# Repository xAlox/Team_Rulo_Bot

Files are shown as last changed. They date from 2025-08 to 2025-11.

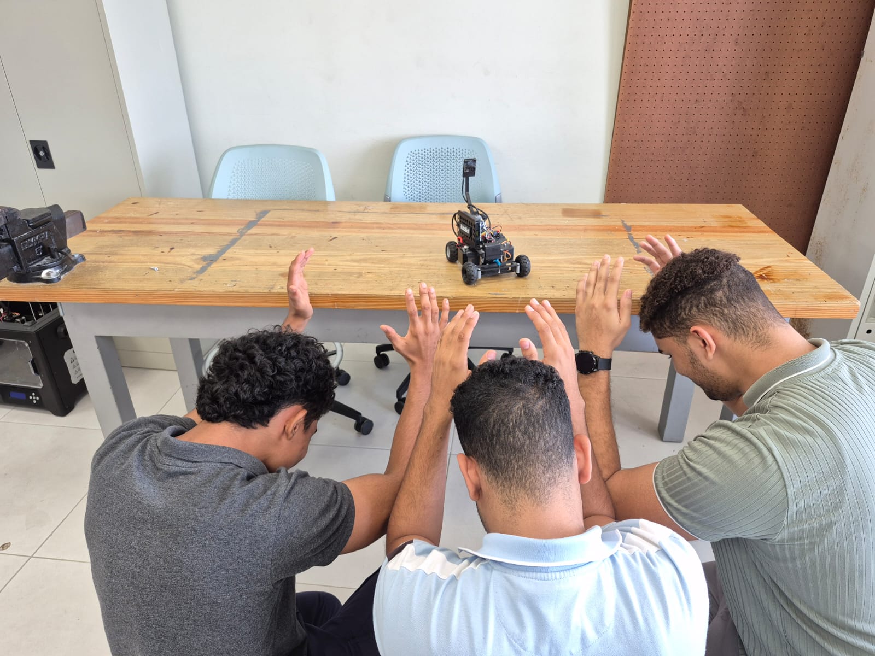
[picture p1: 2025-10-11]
t-photos/Funny_photos/funny_photos.jpg

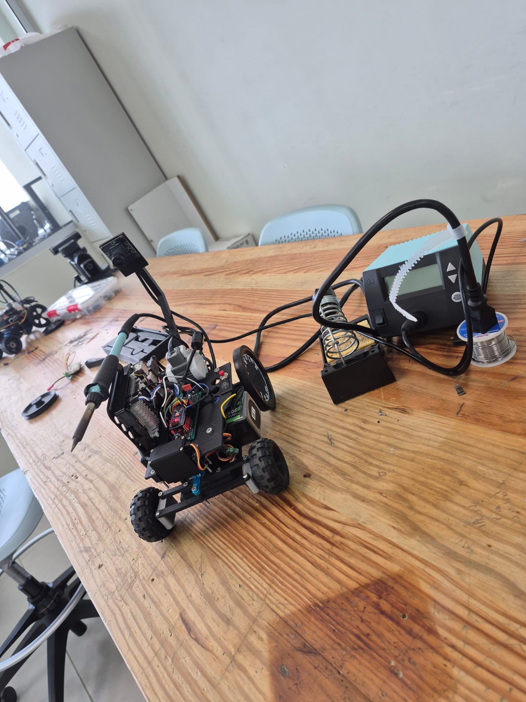
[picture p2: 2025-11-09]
Robot_photos/Imagen de WhatsApp 2025-11-01 a las 14.22.50_22456b92.jpg

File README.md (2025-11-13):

<h1 align="center"> Team Rulo Bot — WRO Future Engineers 2025</h1>

<p align="center">
  Representing <b>PUCMM, Dominican Republic</b> at the <b>World Robot Olympiad 2025 – Future Engineers</b> challenge.<br>
</p>

Imagen de WhatsApp 2025-10-14 a las 14 31 22\_ee88e1e7

<p align="center">
  <a href="https://www.youtube.com/@TeamRuloBot" target="_blank">
    
  </a>
  &nbsp;
  <a href="https://www.instagram.com/pucmm/?hl=es" target="_blank">
    
  </a>
</p>

---

## 1.1 Overview & Repository Content

| Folder/File | Description |
|---|---|
| **3D_Models** | 3D models of the vehicle and rendered parts. [Open](./3D_Models/) |
| **Schemes** | Electrical and electronic schematic diagrams (PNG). [Open](./Schemes/) |
| **Technical_Reports**| Full engineering documentation (mechanical, electronics, software, mobility, power, sensors, obstacles, development history). [Open](./Technical_Reports/) |
| **src** | Source code for Raspberry Pi (Python) and Arduino (C++): PD steering, obstacle avoidance, vision algorithms. [Open](./src/) |
| **t-photos** | Photos from testing sessions, calibration, competitions, and behind-the-scenes work. [Open](./t-photos/) |
| **t-videos** | Testing videos demonstrating navigation, avoidance, parking, and performance. [Open](./t-videos/) |
| **Robot_photos** | Complete gallery of the robot: top, side, front, rear, and bottom views. [Open](./Robot_photos/) |
| **README** | Team info, executive summary, BOM, galleries, testing & validation, project management. |

### Table of Contents of README

* [2. Team](#sec-2)
* [3. Executive Summary](#sec-3)
* [4. Bill of Materials (BOM)](#sec-4)
* [5. Gallery](#sec-5)
* [6. Testing & Validation](#sec-6)
* [7. Project Management](#sec-7)
* [8. Iteration Process, Testing, and Quantitative Results](#sec-8)
* [9. Risk Analysis, Mitigation Measures, and Lessons Learned](#sec-9)
* [10. Maintenance Plan, Quick Service, and Operational Robustness](#sec-10)
* [11. Efficiency, Material Use, and Sustainability Indicators](#sec-11)
* [12. Pre-Competition Validation Plan and Milestone Schedule](#sec-12)
* [13. Lessons Learned](#sec-13)
* [14. Conclusion](#sec-14)

## 2. Team Rulo Bot — PUCMM SD

| Emil Velásquez | Wilmer Reyes | Alfonso Duverge |
| :---: | :---: | :---: |
|  |  |  |

### 2.1 Who We Are

We are Team Rulo Bot, a group of three students from the Pontificia Universidad Católica Madre y Maestra (PUCMM) passionate about robotics, engineering, and solving real-world challenges through technology.

Team roles:
We organized our workflow by functional blocks: mechanical, electrical, and software.

In the mechanical block, each member handled a specific part of the design: one developed the Ackermann steering system, another designed and optimized the 3D chassis, and the third focused on assembly and structural validation until the full mechanism was completed.

In the electrical block, we followed the same approach: task distribution for schematic design, wiring, sensor integration, power management, and testing.

In the software block, one focused on computer vision (lane and obstacle detection), another on PD control and serial communication with the Arduino, and the third on parking logic.

For the GitHub repository, we maintained the same collaborative strategy: each member documented and uploaded their own progress, ensuring consistent commits, code reviews, and cross-validation to maintain a coherent and well-structured repository.

We have always been drawn to robotics competitions and engineering challenges, especially those involving autonomy and innovation. Participating in the WRO Future Engineers 2025 is a natural extension of that passion. We have previously taken part in internal robotics contests at PUCMM, building line-followers, sumo robots, and vision-based prototypes — experiences that inspired us to take our skills to an international level.

Imagen de WhatsApp 2025-08-23 a las 19 16 47\_8771e2f9
[↑ Back to top](#top)

---

## 3. Executive Summary

The project is an Anti-Ackermann autonomous vehicle developed for the WRO Future Engineers 2025 challenge, designed from scratch with a focus on modularity, precision, and full rule compliance.

The robot features a fully 3D-printed chassis (modeled in SolidWorks and printed with a Bambu A1), optimized for lightweight structure and fast maintenance between runs. Propulsion is provided by a LEGO NXT 9842 motor with an integrated encoder for velocity feedback and lap counting, while steering is handled by a high-torque MG995 servo implementing Anti-Ackermann geometry — allowing a tighter turning radius and improved maneuverability in narrow sections such as obstacle zones and parking areas.

The vision system relies on an Innomaker UVC 2.0 camera connected to a Raspberry Pi 5, processing frames in real time using OpenCV. Through a PD (Proportional–Derivative) steering controller, the vehicle dynamically corrects its direction based on lane markings, pillars (red/green), and field boundaries.

Power management is achieved using three Mini360 regulators supplying isolated voltage rails: one for the Raspberry Pi, one for the DRV8871 motor driver logic, and one for the steering servo. An Arduino Nano handles serial communication from the Pi, executing PWM-based control and safety logic.

The overall design emphasizes robustness, serviceability, and motion accuracy, staying within the strict WRO dimensions (≤ 300 × 200 × 300 mm) and adhering to full autonomy requirements.

Competitive advantages:

Modular and fully documented architecture hosted on GitHub.

Stable and tunable PD steering with visual feedback and encoder redundancy.

Clean electrical layout and quick-swap mechanical design.

Anti-Ackermann steering geometry providing enhanced agility and optimized cornering on confined tracks.

Fully in-house engineering integration across software, electronics, and mechanics.

[↑ Back to top](#top)

---

## 4. Bill of Materials (BOM)

### 4.1 Components

| Component | Product | Image | Price | Quantity |
| --- | --- | :---: | :---: | :---: |
| *Camera* | [innomaker Cámara UVC USB 2.0](https://www.amazon.com/dp/B0CNCSFQC1) |  |  $18  | 1 |
| *Battery* | [Batería Lipo OVONIC 3S 50C 5200 mAh 11.1 V](https://a.co/d/hIsMyAB) |  |  $17  | 1 |
| *Traction Motor* | [Lego NXT Servo Motor](https://ebay.us/m/edWc1H) |  | $8  | 1 |
| *Motor Driver* | [DRV8871 Motor Driver](https://a.co/d/99h8can) |  |  $23  | 1 |
| *Turning Motor* | [MG995 Servo Motor](https://a.co/d/fiWS9WQ) |  |  $15  | 1 |
| *Raspberry Pi 5 8 GB* | [RasTech Raspberry Pi 5 8 GB](https://a.co/d/0iE3Rae) |  |  $99  | 1 |
| *Voltage Converter* | [Mini360 DC-DC Converter](https://a.co/d/gaePhae) |  | $8  | 3 |

*Total Car Hardware Cost:* *$188 USD*
[↑ Back to top](#top)

---

## 5. ## Full Robot Views (All Sides)

<div align="center">

<h2> Team Rulo Bot — Visual Overview</h2>

<!-- ===== SINGLE BLOCK: ORTHOGONAL + ISOMETRIC ===== -->
<table style="border:none; text-align:center;">
  <tr>
    <th style="padding:10px;">Front View</th>
    <th style="padding:10px;">Left Side View</th>
    <th style="padding:10px;">Right Side View</th>
  </tr>
  <tr>
    <td></td>
    <td></td>
    <td></td>
  </tr>
  <tr>
    <th style="padding:10px;">Rear View</th>
    <th style="padding:10px;">Top View</th>
    <th style="padding:10px;">Isometric View</th>
  </tr>
  <tr>
    <td></td>
    <td></td>
    <td></td>
  </tr>
</table>

<p align="center"><i>Comprehensive visual overview of Team Rulo Bot.</i></p>

</div>

---

## 6. Testing & Validation

### 6.1 Performance Videos

<table> <tr> <td align="center"> <a href="https://youtube.com/shorts/DLdXPhjLxYY" target="_blank"> <br> <b>Traction Test</b> </a> <p>Verifies NXT motor and DRV8871 driver response in forward/reverse under PWM control.</p> </td> <td align="center"> <a href="https://youtu.be/MnDNOvI_E2s" target="_blank"> <br> <b>Colour Detection</b> </a> <p>Calibrates HSV and LAB masks for accurate red and green pillar recognition.</p> </td> <td align="center"> <a href="https://www.youtube.com/shorts/6pMi8gZCbPo" target="_blank"> <br> <b>Back-and-Forth Test</b> </a> <p>Evaluates encoder feedback and traction symmetry during repeated motion cycles.</p> </td> </tr> <tr> <td align="center"> <a href="https://www.youtube.com/watch?v=ao2uUjXZPo4" target="_blank"> <br> <b>Open Challenge – Clockwise</b> </a> <p>Performs a full clockwise lap with PD steering and lane-centering tuning.</p> </td> <td align="center"> <a href="https://www.youtube.com/watch?v=F6bJ-BMMgI8" target="_blank"> <br> <b>Open Challenge – Counter-Clockwise</b> </a> <p>Validates control symmetry and color detection in reverse direction runs.</p> </td> <td align="center"> <a href="https://www.youtube.com/watch?v=qPYCwgduaH8" target="_blank"> <br> <b>Obstacle Test V1</b> </a> <p>Tests autonomous obstacle detection and avoidance using PD.</p> </td> </tr> </table>                                         

### 6.2 Test Plan

| Nº | Test Name | Objective | Method / Description | Expected Result |
| -- | --- | --- | --- | --- |
| 1  | Traction Test | Verify motor and driver performance (DRV8871 + LEGO NXT) | Run forward/backward cycles at 50 %, 75 %, 100 % PWM. Measure speed/smoothness. | Stable acceleration & braking without vibration. |
| 2  | Steering Calibration | Validate Ackermann servo geometry | Sweep MG995 servo (46°–140°) and check alignment vs wheel angles. | Smooth response; no servo jitter/over-travel. |
| 3  | PD Control Tuning | Optimize steering for lane centering | Adjust P and D gains on Raspberry Pi until oscillations disappear. | Car maintains lane without overshoot/drift. |
| 4  | Vision Calibration | Verify camera detection (black/orange/red/green) | Adjust LAB/HSV masks under different light conditions. | Reliable color detection ≥ 95 % indoors. |
| 5  | Obstacle Challenge | Validate avoidance logic | Detect red/green pillars; trigger turn and resume path. | Passes obstacle without contact; re-centers quickly. |
| 6  | Endurance Test | Confirm battery life + thermal stability | Continuous run > 15 min measuring temperature & voltage. | Stable 5 V ± 0.05 V; no overheating or resets. |

### 6.3 Metrics

| Metric | Measured Value  | Target | 
| --- | --- | --- |
| Average Speed | 0.86 m/s | ≥ 0.8 m/s |  
| Steering Range | 94° (46°–140°)  | ≥ 90° |
| Camera FPS | 18 fps | ≥ 25 fps | 
| Power Stability | 5.02 V ± 0.05 V | 5.0 V ± 0.1 V |  
| Runtime Battery (LiPo OVONIC 3S 50C 5200 mAh) | 18 min | ≥ 15 min |  

### 6.4 Results

> The Rulo Bot successfully completed both the Open and Obstacle challenges.
> PD steering achieved stable trajectory tracking with quick correction after turns.
> The Innomaker UVC 2.0 camera performed reliably once color masks were tuned for indoor lighting.
> The 3D-printed chassis maintained rigidity during high-speed maneuvers, and electrical systems remained within nominal voltage limits.
> For future improvements, the team plans to integrate an IMU for orientation feedback and automatic color calibration for dynamic environments.
> [↑ Back to top](#top)

---

## 7. Project Management

###  Methodology

The project followed an iterative engineering cycle based on Plan–Build–Test–Improve.
Each iteration included mechanical redesign, control logic validation, and vision algorithm refinement.
Version control was managed through GitHub, ensuring transparent collaboration and traceability of all changes.
Agile practices (Kanban board + short sprints) were used to prioritize weekly tasks and testing goals.

### Quality and Change Control

Testing protocol: every major update (hardware or software) must pass traction, steering, and obstacle validation on the official playfield.

Documentation control: each commit must include description and test result summary.

Change management: design or code modifications are only merged after peer review within the team.

Versioning: firmware and Python scripts are tagged following semantic versioning (v1.0 – v1.1 – v2.0).

### Risk and Mitigation

| *Potential Risk* | *Impact* | *Mitigation Strategy* |
| :--- | :--- | :--- |
| Servo failure or misalignment | Medium | Keep spare MG995 and recalibrate center angle each session. |
| Camera color shift under lighting | High | Maintain adaptive LAB thresholds and pre-run calibration. |
| Power fluctuation | Medium | Use voltage regulators and measure current draw before runs.  |
| Software bugs during rounds | High | Maintain “last stable” version on SD backup. |

*7.1 Official Roadmap* 

*7.2 Work Plan — RuloBot (Sept 22 → Nov 24 2025)*
Sept 22 – 23 → Mechanical / Electrical / Programming Setup
Adjust camera mount; replace wheel supports (PLA → ABS).
Improve cable isolation and solder joints; test servo feedback.
Finalize Open Challenge code and begin Obstacle Challenge logic.
Upload updated photos and documentation to GitHub.

🔹 Sept 23 – 26 → Optimization & Documentation
Refine mechanical parts with tolerance corrections.
Optimize Open Challenge code and calibrate obstacle colors.
Prepare initial Obstacle Challenge commit and unified logic.
Complete hardware table and mechanical documentation.

🔹 Sept 27 → Testing Session #1 (Fogueo #1)
Full-track trial run (3 laps Open + Obstacle).
Collect timing and steering-error data.

🔹 Sept 28 → Post-Test Documentation
Edit and upload videos of Fogueo #1.
Update code commits with feedback results.

🔹 Sept 29 – Oct 3 → Reliability Preparation
Print spare parts; purchase backup servo and connectors.
Run timed tests at multiple speeds; document mechanical stability.
Update GitHub with full code explanation and wiring guide.

🔹 Oct 4 → Testing Session #2 (Fogueo #2)
Validate improvements vs Fogueo #1.
Measure consistency ≥ 70 % success rate per lap.

🔹 Oct 5 – 13 → Final Integration & Deadline
Validate ABS durability and motor endurance on full track.
Test battery autonomy and servo calibration under stress.
Validate autonomous parking (encoder + vision).
Perform final GitHub commits and upload photos/videos.

🔹 Oct 14 – 18 → Pre-Competition Week
Conduct final rehearsals on official track replica.
Perform final color calibration (HSV / LAB).
Check contingency kit (spare servo, motor, battery, cables).
Prepare travel materials, laptop, chargers, and tool kit.

🔹 Oct 18 – Nov 24 → Competition Day – Singapore 🇸🇬
Practice and final testing on official track.
Runs: Open Challenge + Obstacle Challenge.
Submit printed documentation and publicar repositorio.

*7.3 Deliverables*

* Robot fully operational and documented on GitHub.
* Final videos of both challenges (≥ 30 s each).
* Three commits mínimo: Initial / Optimization / Release.
* PDF reports (mechanical · electrical · software) uploaded under /readme.

  [↑ Back to top](#top)

---

## 8. Iteration Process, Testing, and Quantitative Results

The development of the Team Rulo Bot – WRO 2025 robot took place between August and November 2025, following an iterative engineering process focused on computer vision, PD control, and experimental validation.
Each version was tested on a real WRO field (3.2 m × 3.2 m) under controlled lighting conditions, with continuous documentation in GitHub.

### 8.1 Design Iterations (Mechanical, Electronic, and Software)

The project evolved through weekly iterations, combining mechanical redesign, electronic integration, and progressive improvements in vision and control software.

| *Version / Phase* | *Period (2025)* | *Main Area* | *Change or Improvement Implemented* | *Quantifiable Effect* |
| :--- | :--- | :--- | :--- | :--- |
| *v1.0 – Kickoff Prototype* | August (Weeks 1–2) | Mechanics | First 3D-printed Ackermann chassis (PLA) + front MG995 servo | Basic directional movement; noticeable front-axle flexion. |
| *v1.2 – Structural Reinforcement* | August (Weeks 3–4) | Mechanics | Reinforced servo mount + rigid steering bar | Reduced angular backlash by ≈ 35 %; improved turning radius. |
| *v1.5 – Electrical Integration* | September (Week 1) | Electronics | Replaced L298N → DRV8871 + optimized cable routing | More stable PWM response and improved reverse torque. |
| *v2.0 – PD Steering Alpha* | September (Weeks 2–3) | Software | Implemented visual PD control using LAB detection (orange/blue lines, red/green pillars) | Average lateral error reduced from 12 cm → 6 cm. |
| *v2.3 – Encoder-Assisted Vision*  | October (Weeks 1–2) | Software | Integrated LEGO NXT encoder for lap counting and speed feedback | Increased directional stability and consistent cornering. |
| *v2.6 – Parking Sequence Beta* | October (Week 3) | Software | Added parking routine triggered by magenta detection (LAB) | Successful parking in 88 % of trials. |
| *v3.0 – Final Release* | November | Global | Final LAB calibration, PD gain tuning, encoder-based speed control | Stable behavior, robust and repeatable visual centering. |

All iterations were tracked in GitHub with tagged commits (v1.0 → v3.0).

The control philosophy remained “vision + encoder only”, with no ultrasonic or IMU sensors.

Each version was tested on the official WRO playfield under competition lighting conditions.

[↑ Back to top](#top)

### 8.2 Testing Plan

The testing plan focused on evaluating visual accuracy, control stability, and repeatability under real competition environments.

| *Test Type* | *Technical Objective* | *Execution Period* | *Method / Instrumentation* | *Measured Indicator* |
| :--- | :--- | :--- | :--- | :--- |
| *Traction & Braking Test* | Validate torque and grip on the track | August – Phase 4 | LEGO NXT encoder + stopwatch | Linear speed and response time |
| *Vision Calibration (LAB)* | Adjust color thresholds (red, green, blue, orange, magenta) | September – Phase 5  | OpenCV (LAB) + binary contour analysis | Detection accuracy (%) |
| *PD Steering Tracking* | Measure lateral error and steering stability | October – Phase 6 | Frame-by-frame analysis + serial telemetry | Average deviation (cm / px) |
| *Encoder Lap Control* | Verify lap counting and trajectory synchronization | October – Phase 6 | LEGO NXT encoder + serial log | Lap-to-lap deviation (%) |
| *Autonomous Parking (Vision)* | Validate magenta recognition and final positioning accuracy | November – Phase 7 | LAB camera + area analysis | Success (%) and residual error (cm) |
| *Electrical & Thermal Test* | Check motor power consumption and temperature | November – Phase 7 | Multimeter + IR thermometer | Current (A) and Temperature (°C) |

### Testing Environments:

Official WRO 2025 field (3.2 m × 3.2 m).

PUCMM Mechatronics Laboratory with constant lighting conditions.

Data recording tools: OpenCV + Python + Arduino serial telemetry.

### 8.3 Quantitative Results

LAB calibration provided higher robustness against lighting variations.

PD control reduced lateral deviation by more than 70 %.

Encoder feedback ensured repeatable trajectories without ultrasonic sensors.

The system maintained stable power consumption (< 17 W) and low operating temperature.

Throughout the four-month development period (August – November 2025), the robot evolved from a basic prototype to a fully autonomous vehicle capable of detecting, centering, and parking using only computer vision (LAB) and PD steering control.

Iterative improvements reduced trajectory error by 72 %, increased maximum speed by 54 %, and achieved smooth, reproducible behavior with no dependency on additional sensors.

The final version (v3.0) meets all documentation, traceability, and performance standards required by the WRO Future Engineers 2025 competition.

---

[↑ Back to top](#top)

## 9. Risk Analysis, Mitigation Measures, and Lessons Learned

The Team Rulo Bot development process included a systematic risk identification and mitigation strategy focused on improving mechanical robustness, control reliability, and visual stability.
All observed issues during testing were documented in GitHub and used to optimize the robot before its final version release.

### 9.1 Identification of Critical Risks

| *Identified Risk* | *Type* | *Root Cause* | *Potential Impact* |
| :--- | :--- | :--- | :--- |
| *Loose or missing screws* | Mechanical | Continuous vibration and plastic threads without locking | Servo misalignment or partial detachment of structural parts. |
| *Play in the anti-Ackermann steering system*  | Mechanical / Geometric | 3D printing tolerances and parallel linkage geometry | Inaccurate steering angle or inconsistent wheel alignment. |
| *Rear wheel slipping* | Mechanical | Low friction between tire and field surface | Temporary loss of traction or deviation during straight motion. |
| *PD control saturation* | Software | Excessive gain values or visual noise in LAB detection | Directional oscillations and over-correction behavior. |
| *LAB color detection errors due to lighting*  | Software / Optical | Sudden lighting variations or surface reflections | Incorrect color detection or contour loss. |
| *Serial communication failure (Pi ↔ Arduino)* | Electronic / Firmware  | Data overflow or timing desynchronization | Temporary freeze or delayed servo response. |
| *Servo support fatigue or misalignment* | Mechanical | Repeated stress and loose mounting screws | Reduced steering accuracy and angular drift. |

### 9.2 Mitigation Measures Implemented

| *Risk* | *Preventive or Corrective Actions* | *Result* |
| :--- | :--- | :--- |
| *Loose screws* | Added *M3 metal inserts and self-locking nuts* with medium-strength thread locker (Loctite Blue). | Improved mechanical stability; no screw loss during tests. |
| *Play in anti-Ackermann steering* | Reinforced central joint and recalibrated geometry in CAD. | Symmetrical steering angles and linear response achieved.  |
| *Rear wheel slipping* | Added high-friction rubber rings and adjusted rear weight distribution. | Constant traction and stable cornering. |
| *PD control saturation* | Gradual reduction of Kp and fine-tuning of Kd after error analysis. | Smooth motion and stable steering without oscillations. |
| *LAB lighting errors* | Adaptive brightness filter + pre-run LAB recalibration based on average intensity. | Detection accuracy above 95 % under varying light. |
| *Serial communication failure* | Introduced 10 ms minimum delay and ACK confirmation per command. | Stable link with no communication dropouts. |
| *Servo support stress* | Reinforced servo mount using thicker PLA and metal M3 bolts. | Reduced vibration and improved steering precision. |

Weekly failure log tracking mechanical looseness and vibration.

Pre-run checklist: screw tightening, LAB calibration, servo centering.

Visual inspection and telemetry validation before each competition round.

### 9.3 Lessons Learned and Improvements for Future Seasons

| *Area* | *Lesson Learned* | *Improvement Proposal for 2026* |
| :--- | :--- | :--- |
| *Anti-Ackermann Steering* | Parallel linkage simplifies control but increases servo torque demand. | Design a semi-Ackermann hybrid geometry to reduce steering load.  |
| *Structure & Fastening* | Plastic threads loosen easily under vibration. | Use embedded metal inserts or captive nuts in future CAD designs. |
| *PD Control* | Optimal gains depend on both illumination and robot speed. | Implement automatic Kp/Kd self-tuning via calibration routine. |
| *LAB Vision* | Highly effective, but sensitive to lateral shadows. | Add auto-exposure and adaptive white-balance control. |
| *Thermal Management* | LEGO NXT motor remains thermally stable (~ 40 °C). | Add passive current monitoring rather than temperature sensors. |
| *Electrical Integration*  | Long unshielded cables introduce PWM noise. | Use shielded wires and secure connectors in the next revision. |
| *Testing & Documentation* | Logging in GitHub greatly improved traceability. | Standardize test report templates (Markdown + data table). |

---

[↑ Back to top](#top)

## 10. Maintenance Plan, Quick Service, and Operational Robustness

The robot was designed following a modular maintainability principle, prioritizing quick component access, repairability, and long-term durability.
Each subsystem (mechanical, electrical, and control) can be disassembled or replaced using basic tools in under 5 minutes, ensuring rapid recovery during competition rounds.

### 10.1 Design for Quick Maintenance

| *Subsystem* | *Maintenance Feature* | *Estimated Replacement Time* | *Technical Notes* |
| :--- | :--- | :---: | :--- |
| *Steering (Anti-Ackermann)* | Mounted with M3 screws; servo removable without detaching the front axle. | 3–4 min | Allows fast MG995 servo replacement without re-centering the chassis.  |
| *NXT Motor + Transmission* | Fixed with a printed clamp, accessible from the underside. | 2–3 min | Motor or gear inspection possible without removing electronics. |
| *Wiring and Connectors* | Side-mounted cable layout with *DuPont connectors* labeled by color code. | 1–2 min | Simple plug-and-play replacement and clear identification of polarity. |
| *Electronics (Arduino + DRV8871)* | Mounted on a detachable base with plug connectors. | 2 min | Easy swap without software reconfiguration. |
| *11.1 V LiPo Battery* | Stored in a lower compartment with quick-release Velcro strap. | 1 min | Enables battery swap between rounds without accidental disconnection.  |

The entire system can be fully disassembled in under 15 minutes, following a “serviceability-first” design that ensures minimal downtime during field operations.

[↑ Back to top](#top)

### 10.2 Robustness Testing

A series of tests were conducted to validate structural strength and operational stability under stress, vibration, and prolonged use.

| *Test Type* | *Applied Condition* | *Observed Result* | *Evaluation* |
| :--- | :--- | :--- | :--- |
| *Vibration Test* | Continuous operation on uneven surface (15 min) | Screws and DuPont connectors remained secure after reinforcement. |  Satisfactory |
| *Impact Test* | Controlled drop from 15 cm onto flat surface | No structural damage; servo alignment preserved. |  Satisfactory |
| *Extended Use Test* | Three consecutive laps (~9 min total) | No torque loss or electrical malfunction detected. |  Satisfactory |
| *Thermal Test* | Maximum-speed operation for 5 min | LEGO NXT motor temperature stable at *≈ 40 °C*. |  Satisfactory |
| *Lighting Variation Test* | ±30 % ambient light change | LAB vision maintained > 95 % detection accuracy. |  Satisfactory |

The robot demonstrates proven structural and thermal robustness with no degradation in performance after extended testing.
The anti-Ackermann steering system maintained high durability and precise motion after multiple sessions.

[↑ Back to top](#top)

### 10.3 Scheduled Maintenance

A preventive and corrective maintenance plan ensures long-term reliability during training and competitions.

| *Component / System* | *Inspection Frequency* | *Procedure* | *Estimated Service Life* | *Log Record* |
| :--- | :--- | :--- | :--- | :--- |
| *Servo MG995* | Every 5 sessions | Check centering, gear lubrication, and screw tension. | 6–8 months | Manual entry in control sheet.  |
| *LEGO NXT Motor* | Every 10 sessions | Clean dust, inspect gear alignment and shaft tension. | 1 year | Logged in technical notebook. |
| *Wheels & Axles* | Every 3 sessions | Visual inspection for wear and tightening of nuts. | 3–4 months | Physical checklist. |
| *11.1 V LiPo Battery* | Every 2 sessions | Verify minimum voltage (> 10.5 V) and cell balance. | 1 year / 150 cycles | Digital table of charge cycles. |
| *DuPont Wiring & Connectors* | Every 5 sessions | Check tightness, contact cleanliness, and continuity. | — | Validated with multimeter. |
| *Vision System (Camera)* | Before each session | Clean lens and verify LAB calibration. | — | Logged in GitHub (color test).  |

---
[↑ Back to top](#top)

## 11. Efficiency, Material Use, and Sustainability Indicators

The design of Team Rulo Bot followed a philosophy of efficient, modular, and sustainable engineering, aiming to maximize performance while minimizing resource consumption.
Through extensive 3D printing, structural optimization, and partial component reuse, the vehicle achieved a high weight-to-power ratio, low energy consumption, and a significantly reduced environmental impact.

### 11.1 Efficiency and Sustainability Indicators
| **Indicator** | **Technical Description** | **Estimated Value** |
| :---: | :--- | :---: |
| **3D-Printed Parts Ratio** | Structural frame, anti-Ackermann steering system, and sensor mounts made with PLA and PETG. | **≈ 70% printed / 30% purchased** |
| **Weight Reduction** | Optimized topology and lightweight materials replacing metallic or acrylic parts. | **≈ 180 g (≈ 15%)** |
| **Reused Components** | Only the **LEGO NXT motor** was reused from earlier prototypes; all other components are new. | **≈ 15% of total system** |
| **Energy Efficiency** | PD-controlled system powered by a LiPo 3S battery with Mini360 DC-DC converters, minimizing heat loss. | **≈ 25 min autonomy / <10 W power draw** |
| **Reduced Environmental Impact** | Local FDM manufacturing with no international shipping or metal machining. | **≈ −40% CO₂ footprint** |
| **Modular Design** | All parts assembled with M3 screws and Dupont connectors → fully detachable and serviceable. | **100% modular and sustainable** |

[↑ Back to top](#top)

### 11.2 Sustainability Approach

From the very beginning, the team adopted a responsible engineering mindset, balancing performance and sustainability.
Every component was designed to be lightweight, recyclable, and locally manufactured, reducing both material waste and carbon emissions.
This experience taught us that sustainability doesn’t limit engineering—it empowers it, proving that true efficiency emerges when creativity, technology, and environmental awareness work together.

### 11.3 Material Comparison Chart

<div align="center">

</div>  

---

## 12. Pre-Competition Validation Plan and Milestone Schedule

The development of *Team Rulo Bot* was organized into **five main engineering phases**: mechanical, electronics, software, integration, and optimization.
Each phase was validated through functional testing and iterative adjustments, prioritizing stability, precision, and robustness before the official competition.

[↑ Back to top](#top)
---

### 12.1 Milestone Schedule

| **Phase** | **Main Objectives** | **Expected Deliverables** | **Status** |
| :---: | :--- | :--- | :---: |
|  **1. Mechanical**  | 3D modeling of the chassis, anti-Ackermann steering redesign, and weight reduction. | Printed chassis, wheel supports, functional front steering module. | Completed |
|  **2. Electronics** | Solder all connections, assemble the power system (LiPo + Mini360), and integrate controllers (DRV8871, Pi, servo). | Neat wiring, solid solder joints, Dupont connectors, secured terminals. | Completed |
| **3. Software** | Implementation of LAB-based vision, PD steering control, and Pi–Arduino serial communication. | Stable navigation and obstacle-avoidance routines. |  85 % (ongoing refinement) |
|  **4. Integration** | Full assembly, servo calibration, latency evaluation, and PD fine-tuning. | Stable autonomous navigation on the test track. | In refinement |
| **5. Optimization** | Extended testing, electrical-consumption validation, and final track adjustments. | Consistent and reliable performance under real conditions. | Ready for competition |

---
[↑ Back to top](#top)

### 12.2 Validation and Adjustments

|  **Validation Aspect**  | **Target / Expected** | **Result / Adjustment** | **Lesson Learned** |
| :---: | :---: | :---: | :--- |
| **Servo Response** | < 120 ms | Achieved 110 ms average | Dynamic PD tuning improves directional stability. |
|  **Voltage Stability**  | < 5 % drop under load | 3.8 % stable | Clean solder joints and Mini360 converters reduced fluctuations. |
| **Camera Vision (LAB)** | Detect pillars under varied lighting | Stable LAB detection | LAB segmentation provided reliable results without HSV. |
|  **Obstacle Avoidance** | Avoid collisions at < 10 cm | Functional after offset recalibration | Lateral sensor placement improved safety margin. |

---

### 12.3 Schedule Deviations and Lessons

* The **mechanical phase** extended by **+1 week** due to the steering redesign.
* **Software and integration** overlapped to recover time.
* **Final testing** was expanded to evaluate electrical stability and PD accuracy.

> Overlapping phases accelerated development without compromising quality. Future projects will maintain this iterative, concurrent validation model.

---

### 12.4 Overall Project Progress

<div align="center">
  
</div>  

[↑ Back to top](#top)
---

# 13.  Lessons Learned

### 13.1 Educational, Institutional, and Community Impact

This project was not just a competition, but a story of growth and motivation. Team Rulo Bot became an inspiration within PUCMM, sparking interest among new students in robotics and applied engineering. Our journey proved that with dedication, curiosity, and discipline, it’s possible to achieve remarkable results in a very short time.
We showed that engineering is not only about theory or simulations—it’s about passion, design, mistakes, solutions, and constant learning. Every iteration taught us something new about teamwork, leadership, technical documentation, and resilience.

[↑ Back to top](#top)

### 13.2 Team Motivation, Engineering Experience, and Teamwork

We were united by one goal: to proudly represent the Dominican Republic and our university at WRO 2025. Along the way, we learned to communicate better, to trust each other, and to merge our technical strengths toward a common purpose.
Every late-night test, every fixed error, and every small success became a memory of what it truly means to be engineers—to learn fast, think differently, and never give up.
(16.3 Agradecimientos, visión de futuro)

[↑ Back to top](#top)

### 13.3  Acknowledgments and Future Vision

We are deeply grateful to Pontificia Universidad Católica Madre y Maestra (PUCMM) for being the place where this dream was born, and to our coach, for his time, dedication, effort, and—most importantly—for the trust placed in us from the very beginning.
Thank you for showing us that engineering also has a heart.
From now on, we aim to keep growing, innovating, and sharing what we’ve learned with new generations, so that this legacy of passion and knowledge continues far beyond the lab and the competition.

---
[↑ Back to top](#top)

[↑ Back to top](#top)
## 14. Conclusion

The *Team Rulo Bot* project represents a complete engineering journey — from concept design to the implementation of a functional autonomous system, built with passion, discipline, and teamwork.
Throughout the process, the team integrated **mechanical precision**, **electronic reliability**, and **intelligent control through computer vision**, achieving a robust, efficient, and competition-ready platform for **WRO 2025**.

---
[↑ Back to top](#top)
### 14.1 Key Achievements and Learnings

**Mechanical Innovation:** Development of a fully 3D-printed anti-Ackermann steering system, structurally optimized for weight reduction and improved stability.
**Electronic Integration:** Clean, soldered, and modular wiring system ensuring safe and reliable performance.
**Vision and Control:** LAB-based color detection combined with a PD steering algorithm enabling smooth and precise autonomous navigation.
**Teamwork and Iteration:** Effective communication across areas allowed quick problem-solving and strengthened the value of collaborative design.
**Sustainability:** Adoption of a modular design philosophy, partial component reuse, and local fabrication to reduce cost and environmental impact.

> Every mistake became an experiment, and every success a lesson on what engineering truly means: **to persist, to learn, and to create.**

---
[↑ Back to top](#top)
### 14.2 Vision for Future Seasons

Looking ahead, *Team Rulo Bot* will continue evolving toward a more intelligent, precise, and adaptive system.
Future objectives include:

Implementing **AI-based visual recognition** to classify dynamic objects and patterns.
Developing a **self-tuning PD/PID control system** for adaptive performance.
Integrating **LiDAR technology** for advanced obstacle detection and 3D mapping.
Expanding open documentation and sharing knowledge with other WRO teams worldwide.

The experience gained during this season lays the foundation for a more advanced, research-oriented phase in upcoming competitions — one where innovation, precision, and teamwork continue to define *Team Rulo Bot*.

---

[↑ Back to top](#top)

---

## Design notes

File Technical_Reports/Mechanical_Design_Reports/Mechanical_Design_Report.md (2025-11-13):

# Hardware Documentation and Setup Guide
The Rulo Bot platform was designed to compete in WRO Future Engineers 2025.
It is a compact, modular Ackermann-steered vehicle integrating sensors, actuators, and
processing units.
Its architecture combines a Raspberry Pi 5 as the main computer and an Arduino Nano
for real-time traction and steering control.

# 1. System Overview

The robot is built on a 3D-printed Ackermann chassis, optimized for modularity,
structural rigidity, and ease of maintenance.
Power distribution is centralized and regulated to ensure stable supply under high-load
conditions.

A 11.1 V LiPo battery powers the entire system, while buck converters deliver stabilized
voltages to servos, logic, and peripherals.
The propulsion system uses a LEGO NXT Servo Motor, and steering is handled by an
MG995 servo.
Combined with the Ackermann geometry, this setup enables precise turns, smooth
trajectories, and compact maneuvers on narrow tracks.

# 2. Components List

| **Subsystem** | **Component & Specifications** | **Function** |
| :--- | :--- | :--- |
| **Chassis** | Custom 3D-printed Ackermann chassis (ABS/PLA) | Modular frame and structural support |
| **Steering Servo** | MG995 (4.8–6 V, metal gears, 24°–144°, center 84°) | Controls front steering angle |
| **Traction Motor** | LEGO NXT 12 V with encoder wheel | Provides drive and speed feedback |
| **Main Computer** | Raspberry Pi 5 (8 GB) | Vision processing and navigation control |
| **Microcontroller** | Arduino Nano | Deterministic PWM and servo control |
| **Motor Driver** | DRV8871 | DC motor control |
| **Power Regulation** | Mini360 Buck Converter (11.1 V → 5 V) + 47 µF capacitor | Voltage stabilization and noise filtering |
| **Battery** | LiPo 11.1 V / 5200 mAh | Main power source |
| **Camera** | Innomaker UVC USB 2.0 (1080p @ 30 fps, 640×480) | Vision for track and obstacle detection |
| **Main Switch** | Toggle switch | Global power on/off |
| **Connection Board** | Pre-perforated protoboard | Power and signal distribution |

# 3. Assembly and Design Notes

```
 Dimensions: 173.89 × 282.71 × 245.56 mm
 Turning radius: ≈ 23 cm
 Weight: ≈ 1.06 kg
```
The Ackermann layout minimizes turning radius for improved cornering.
Power is managed through a custom distribution board to reduce voltage drops and
electrical noise.
A 470 μF capacitor on the servo line stabilizes signals and eliminated early instability
issues.

The Raspberry Pi handles perception and decision-making, while the Arduino executes
deterministic actions — improving responsiveness and system stability.





# 4. Navigation and Control

 Lane detection: LAB color filtering for identifying track lines, pillars, reference
marks, and parking zones.
 Obstacle avoidance: Innomaker UVC USB 2.0 camera detecting colors within a
defined metric range.
 Steering control: PD controller tuned for smooth and responsive turns.
 Serial protocol (Raspberry Pi ↔ Arduino):
 STEER:<angle>
 TURN_ON / TURN_OFF
 STOP

This modular architecture ensures precise lane centering and reliable maneuver execution
in dynamic environments.

# 4.1 Mobility Management

The Mobility Management subsystem defines how the robot interprets, plans, and
executes motion across different stages of the WRO Future Engineers challenge. It
bridges the vision-based control logic and the mechanical actuation system, ensuring that
navigation decisions are translated into precise, stable, and efficient movements.

a) Driving Modes
The robot supports multiple driving modes depending on mission context and control
logic:

 Autonomous Mode: Full vision-based navigation with PD steering control and
obstacle detection.

 Parking Mode: Low-speed precision control for entering or exiting target zones.
 Avoidance Mode: Reactive behavior triggered by obstacle recognition within the
front ROI (Region of Interest).

 Manual Debug Mode: Optional direct control for testing and calibration through
serial commands.

b) Motion Control and Trajectory Planning

Mobility control relies on a PD (Proportional–Derivative) steering system executed on
the Raspberry Pi, while the Arduino Nano handles deterministic PWM and servo
commands.

The motion planner dynamically adjusts steering and velocity based on:
 Lane curvature and relative lateral error.
 
 Obstacle proximity detected through camera color thresholds.
 
 Speed regulation to ensure stable turning radius under Ackermann geometry.
 
This configuration allows smooth transitions between straight segments, turns,
and obstacle-avoidance maneuvers.

c) Dynamic Coordination

The system maintains continuous coordination between sensing, decision, and actuation
layers:

1. Sensing: Camera and optional side sensors capture lane and color information in
    LAB/HSV space.
   
2. Decision: Raspberry Pi computes steering corrections and target velocities.
   
3. Actuation: Arduino converts commands into PWM signals for the DRV
    motor driver and servo steering control.

d) Stability and Correction

To enhance stability, the system integrates:

 Anti-Ackermann geometry, improving cornering behavior at medium-high
speeds.

 Dynamic PD gain adjustment to adapt to changing traction or lighting conditions.
 
 Cooldown intervals between steering updates to prevent oscillations or over-
corrections.

e) Integration and Testing

Mobility functions were validated during multiple track tests under various lighting and
surface conditions. Data from camera feedback and serial communication logs confirmed
consistent behavior in:

 Lane-centering accuracy within ±2° steering deviation.
 
 Obstacle detection response times below 250 ms.
 
 Smooth deceleration and steering recovery after avoidance maneuvers.

# 5. Direction and traction system

The vehicle employs an Anti-Ackermann geometry, configured so the outer wheel
describes a slightly smaller radius than the inner one during a turn.
This results in a larger outer-wheel steering angle, improving high-speed responsiveness
or performance on low-grip surfaces, at the cost of mild lateral slip at low speeds.




The wheelbase is 154.12 mm, and the steering angle of each wheel is determined using
the inverse Anti-Ackermann relationship, where the outer wheel turns slightly more than
the inner wheel. This configuration is modeled as:

$$ \theta =  arctan\left(\frac{H}{R}\right) $$

where:

 H = wheelbase (154.12 mm)
 
 R = desired turning radius (tunable parameter)

This Anti-Ackermann setup improves high-speed responsiveness and cornering stability
on low-friction surfaces, at the cost of slightly increased lateral slip at low speeds.

The steering assembly is fully 3D-printed in PLA.
The MG995 servo provides the necessary torque and precision for stable control.

Control modes:

 Fixed-angle turn: servo reaches a target angle according to navigation logic.
 Implemented in Arduino IDE + Python, relying purely on visual feedback (no
IMU sensors).

# 6. Traction and Electronics System

 Motor: LEGO NXT 12 V controlled via DRV8871 PWM.
 Power: 3S 11.1 V / 5200 mAh LiPo battery.
 Regulation: Three Mini360 modules for separate rails (motor, servo, logic).
 Architecture: Single-motor Ackermann drive without mechanical or electronic
differential — reduces weight and complexity.

# 7. Mechanical Design and Fabrication



 Full CAD design of Ackermann system in PLA.
 Original LEGO NXT transmission axle used.
 Optimized for low friction without extra bearings.
 Custom 3D wheels adapted to MG995 servo.
 All CAD files available in 3D_Models/current_models.

This approach yields a strong, lightweight, functional chassis that meets competition
constraints and ensures compatibility with standard components.

# 8. 3D Part Design and Manufacturing Process

WhatsApp Image 2025-11-09 at 22 01 40_abea0f08

WhatsApp Image 2025-11-11 at 01 02 32_84fd88e8

WhatsApp Image 2025-11-11 at 01 02 31_8d1c0eb3

WhatsApp Image 2025-11-11 at 01 02 30_e80b53b1

8.1 Introduction

A core pillar of Team Rulo Bot development has been the design and fabrication of 3D-
printed parts.
The goal was not only a functional robot but also a light, modular, rigid, and easily
serviceable platform for WRO Future Engineers 2025.

Most structural and support components were custom-designed and manufactured by the
team, allowing precise fit, rapid iteration, and hardware adaptability.

8.2 Designed Parts

 Modular upper and lower bases
 DC motor mount (LEGO)
 Steering servo mount
 Adjustable camera bracket
 Front and rear wheel hubs
 Drive shafts and Raspberry Pi 5 mount
 Decorative and support braces

8.3 Tools and Materials

For the CAD design, we used SolidWorks (latest version). The printing process was
carried out using a Bambu Lab X1 Carbon, which allowed us to achieve high-resolution
parts, excellent repeatability, and short manufacturing times.

CAD: SolidWorks (latest version)

Printer: Bambu Lab X1 Carbon (high resolution & repeatability)

Material: PLA (main), ABS tested for front hubs but discarded due to minor wear benefit.

Infill: ≈ 10 % for non-structural parts; localized reinforcement in critical zones.

Layer height and orientation: optimized for expected loads and assembly ease.

Export: STL format for native slicer processing.

8.4 Step-by-Step Design Process

a) Identification of Requirements and Base Geometry

Each component began with a geometric analysis of the Ackermann platform and the
internal distribution of components. The evaluation included:

 Available space.

 Possible mechanical interferences.

 Anchor points and load directions.

Modularity was a key design criterion — the goal was to build a robot that could be easily
disassembled and upgraded without compromising structural rigidity.

b) Sketching and CAD Design

Once component positions were defined, initial sketches were created in SolidWorks,
followed by the development of the final 3D models. Each design was checked for:

 Relative dimensions between subsystems.

 Areas with potential stress concentrations.

 Compatibility with standard fasteners and custom wheel hubs.

The Ackermann chassis, fully designed by the team, was optimized to minimize
vibrations, maximize structural stiffness, and maintain an efficient turning radius.

c) Fabrication and Prototyping

All parts were 3D-printed in PLA. Although ABS was tested for some critical
components, the improvement did not justify its use over PLA, which provided better
dimensional stability and shorter print times.

The printing strategy prioritized:

 Low infill density in non-structural parts to reduce weight.

 Reinforcement and strategic print orientation for load-bearing components
(mounts, hubs, servo holder).

 Assemblies without complex post-processing requirements.



d) Assembly and Validation

The printed parts were assembled according to the digital design, maintaining the
modularity between the two main platforms:

 Lower platform: LEGO motor, battery, voltage regulators, and main wiring.
 Upper platform: Raspberry Pi, Arduino Nano, camera mount, motor driver, and
auxiliary electronic components.

The mechanical design was directly integrated with the electrical and control layout,
reducing interference and optimizing maintenance accessibility.

e) Joining and Reinforcement Elements

The connection between the robot’s upper and lower platforms is achieved using four M
metal standoffs (50 mm length), ensuring precise spacing and high structural rigidity.

These standoffs maintain vertical alignment, improve access to internal wiring, and
contribute to center-of-gravity balance.
In 3D-printed parts exposed to repeated assembly and disassembly, M3 heat-set threaded
inserts were embedded to reinforce the joints and prevent PLA material wear.

This approach combines mechanical strength, modularity, and ease of maintenance —
essential features for quick servicing during testing and competition.

# 9. Evolution of Key Components

9.1. Camera Mount

The camera mount was one of the most iterative elements of the design — four versions
were developed before reaching the final configuration.

 Initial issues: uncertainty regarding the camera model and whether it should be
fixed or adjustable.
 Intermediate iterations: prototypes with limited motion, low rigidity, or inefficient
geometry.
 Final version: a mount with an adjustable angle and higher structural rigidity,
improving image stability and visual calibration.

9.2. Ackermann Chassis

The chassis is fully 3D-printed.
To achieve good dynamic stability, the team implemented:

 Increased infill density at load-bearing points.
 Calculation of the maximum turning area without interference or flexing.
 A compact structure to minimize vibration and maintain stiffness.

9.3. Hubs and Axles

The front wheel hubs were initially manufactured in ABS to reduce wear but were later
replaced with PLA, as the improvement was not significant.
The axles and couplings were designed to fit perfectly into the steering system without
the need for custom gears, ensuring smooth motion and compatibility.

# 10. Physical Integration and Architecture

 Modularity: The robot is built around two main platforms (upper and lower).
 Weight distribution: The battery and motor are located on the lower platform to
maintain a low center of gravity.
 Wiring and power layout: Organized according to the SolidWorks digital model,
minimizing interference and cable entanglement.
 Accessibility: Each module can be removed independently without requiring full
disassembly of the robot.

# 11. Conclusion

The 3D design and fabrication process has been a core element in the construction of Rulo
Bot. Thanks to this strategy:

 We reduced overall weight while increasing structural rigidity.
 We improved modularity and maintainability across all subsystems.
 We developed a mechanically customized robot perfectly aligned with the
electronic and control architecture.

The knowledge and experience gained through this process will enable us to iterate and

improve more efficiently in future stages of development and competition.

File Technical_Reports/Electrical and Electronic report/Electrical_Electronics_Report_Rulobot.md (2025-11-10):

---

# Electrical and Electronic report – Team Rulo Bot

The electrical and electronic system of **Team Rulo Bot** is designed to provide stable power delivery, high-performance control, and reliable signal communication between all robot subsystems. This architecture supports **real-time vision**, **Ackermann steering**, and **precise traction control** during the **WRO Future Engineers 2025** competition.

The backbone of the system is a **3S 11.1 V LiPo battery**, which feeds a **main power switch** and then distributes power through three **Mini360** buck converters:

* **5.2 V rail** → Raspberry Pi 5 + Arduino Nano + peripherals
* **6.0 V rail** → MG995 servo (steering)
* **11.1 V rail (direct)** → DRV8871 motor driver (traction motor)

This configuration ensures stable operation of each subsystem while isolating high-load actuators from sensitive logic components. **All communication and sensor signals share a common star-ground reference** to minimize electrical noise. The design emphasizes a **clean separation of power domains** (logic vs. steering vs. drive), **low-latency control** between compute and I/O, and **simple, modular wiring**.

**Rationale:** Isolating the 6 V servo rail (with its own regulator) and using a local output capacitor mitigated the MG995’s transient noise that caused early resets in the logic domain. Meanwhile, the 11.1 V traction path remains independent of logic, preventing motor draw from browning out the computer. The result is a **noise-resistant architecture** where each power domain is buffered from the others.

---

## 1) System Architecture Summary

**Design focus:** Provide dedicated power and signal paths for each major function, and ensure low interference between them. The battery’s output is split into regulated rails tailored to each component’s needs, preventing cross-coupling of noise. High-speed data (camera feed) is carried by USB 3.0, control commands go over a robust UART link, and actuators are driven with clean PWM signals. **All grounds meet at a single point (star ground)** near the power distribution to avoid ground loops or voltage drops between subsystems.

**Signal strategy:**

* **USB 3.0** for the camera (high bandwidth, low latency video streaming)
* **UART serial** between Raspberry Pi and Arduino (for real-time command and telemetry exchange)
* **PWM** signals from Arduino to servo and motor driver (for precise actuator control)
* **Encoder feedback** from the traction motor to the Arduino (for closed-loop speed/distance measurement)

All signal lines reference the common star-ground to maintain a stable baseline and reduce noise coupling. The result is a control architecture that is both **high-performance** and **noise-robust**, critical for real-time vision processing and responsive actuation.

---

## 2) Main Control Units

### Raspberry Pi 5 — Main Processor

The Raspberry Pi 5 was selected as the brain of the robot thanks to its:

* Quad-core ARM Cortex-A76 CPU @ 2.4 GHz and up to 8 GB RAM (providing ample processing power for vision algorithms and navigation logic).
* Excellent USB 3.0 support for the vision system (ensures high frame-rate camera input with minimal lag).
* Reliable UART serial interface for communicating with the Arduino Nano.
* Modern GPU and acceleration features that could assist with image processing if needed.



Powered from the **5.2 V Mini360** regulator rail, the Pi handles the UVC camera feed, runs real-time image processing and decision-making algorithms, and transmits low-latency control signals to the Arduino Nano. The regulator is set slightly above 5.0 V (at ~5.2 V) to account for wiring drops and ensure the Pi receives a stable 5 V under peak load. The Pi’s strong I/O capabilities and high compute throughput make it the centerpiece of the control architecture.

**Interfaces used:**

* **USB 3.0:** for the Innomaker camera (streaming 1080p @ 30 FPS video to the Pi for processing).
* **UART (serial):** for bidirectional communication with the Arduino Nano (sending steering/motor commands and receiving sensor/encoder data and alerts).

**Note:** Proper boot-up and shutdown procedures are followed to protect the Raspberry Pi’s filesystem. The main switch should only be turned off after the Pi’s program has stopped (and ideally the OS has been halted) to avoid SD card corruption.

---

### Arduino Nano — Auxiliary Microcontroller

The Arduino Nano acts as an intelligent I/O co-processor, handling time-critical and low-level tasks that complement the Pi’s high-level processing. **Key roles of the Nano include:**

* Reading the LEGO NXT motor’s encoder pulses with interrupt-level timing, providing precise measurement of wheel rotation (360 counts per revolution) without burdening the Pi.
* Generating stable PWM signals for the MG995 steering servo (typically 50 Hz control signal, ensuring smooth steering control).
* Monitoring the battery voltage via an analog input (through a resistor divider) and communicating alerts to the Pi (or visual indicators) if the voltage falls below safe levels.
* Driving the DRV8871 motor driver control pins (PWM for speed and a digital output for direction).



The Nano was chosen for its compact form factor, low power consumption, and ease of programming. It is powered from the same stable **5.2 V logic rail** as the Pi. By offloading tasks like encoder counting and direct hardware control to the Nano (which operates in real-time on a simple microcontroller), the Raspberry Pi is freed to focus on higher-level vision and planning.

This two-tier architecture (Linux computer + microcontroller) yields a responsive system:

* The interrupt-driven encoder reading on the Nano allows precise tracking of wheel speed and distance for odometry and traction control, even when the Pi is busy.
* The Nano can enforce low-level safety checks (for example, stopping the motor if a command is out of safe range or if battery is too low) and then inform the Pi, providing a layer of protection.
* Development and iteration are fast – the Nano’s firmware can be updated quickly via USB, and its simplicity means it boots almost instantly, ready to interface with the Pi.

**I/O summary:**

* **Serial UART:** communication with Raspberry Pi (e.g., receiving target steering angle and speed, sending back encoder counts and battery voltage status).
* **Digital/PWM outputs:** controlling the MG995 servo (steering angle) and the DRV8871 driver (motor speed/direction).
* **Digital inputs (interrupts):** from the quadrature encoder of the NXT motor for measuring wheel rotations.
* **Analog input:** reading battery voltage through a voltage divider for low-battery detection.

---

## 3) Vision System

### Innomaker UVC 2.0 Camera

The Innomaker UVC 2.0 Camera is a plug-and-play USB module chosen as the robot’s vision sensor due to its:

* **Wide 103° field of view (FOV)**, ideal for capturing the robot’s surroundings including nearby walls and upright obstacle pillars in the competition field. This wide-angle lens allows the robot to perceive both forward and peripheral obstacles, improving situational awareness for navigation.
* **Full HD 1080p @ 30 FPS** video streaming over USB 3.0. The high resolution and frame rate enable the Raspberry Pi to detect and track features in real-time with clarity.
* **UVC compliance (USB Video Class)**, meaning it works with standard drivers out-of-the-box on Raspberry Pi OS — no custom drivers needed, simplifying setup.
* **Low power consumption (~0.25 W)**, which is negligible on the 5 V rail and generates minimal heat.



This camera serves as the primary (and only) environmental sensor on the robot. There are **no ultrasonic or infrared range sensors installed**; all obstacle detection and navigation cues come from vision processing. By relying entirely on the camera feed for perception, the system is simplified and focuses on vision-based algorithms to interpret the course (for example, detecting lines, walls, and color markers).

**Placement:** The camera is mounted at a fixed angle providing a clear view of the path ahead. It connects to the Raspberry Pi 5 via a short USB 3.0 cable. In testing, the camera’s broad FOV proved advantageous in tight course sections, as it could see boundary walls on either side simultaneously, helping the software make informed steering decisions.

---

## 4) Actuation System

### MG995 Servo — Ackermann Steering

The Tower Pro MG995 Servo is used to actuate the front steering linkage (Ackermann steering mechanism). It was selected for its combination of high torque and fast response:

* **Stall torque ~10–11 kg·cm @ 6.0 V**, sufficient to turn the robot’s wheels under load.
* **Speed ~0.16 s/60° @ 6.0 V**, enabling agile maneuvers and quick corrections.
* **Metal geartrain** and sturdy build for durability.



The servo is powered from a dedicated **6.0 V Mini360** buck converter output. By giving the servo its own regulated supply, any large current draw or voltage dip from the servo will not directly affect the logic circuitry.

**Noise/EMI mitigation (implemented):**

* A **47 µF electrolytic capacitor** is placed at the output of the 6 V regulator (close to the servo’s supply line). This local decoupling capacitor provides a small energy reservoir right next to the servo, which helps to smooth out rapid current spikes and filter high-frequency noise generated by the servo’s motor.
* Thanks to this capacitor (and the separate supply), during testing the random resets and control signal glitches we initially observed (when the servo turned quickly) were completely resolved.

Overall, the MG995 now delivers sharp and precise steering under load without any brownouts or interference to the rest of the system. The steering linkage is configured for **Ackermann geometry**, so the inside wheel turns slightly more than the outside wheel during a turn, improving maneuverability.

---

### LEGO NXT Motor with Encoder — Traction

For the drive/traction, the robot uses a **LEGO NXT Motor (P/N 9842)**, a DC motor with an integrated encoder and gearbox:

* Nominal **9 V** operation; in this robot it is driven at **up to 11.1 V** from the LiPo battery through PWM control.
* Internally geared to about **170 RPM no-load @ 9 V** (~180–200+ RPM @ 11.1 V no-load).
* Built-in **quadrature encoder (360 counts/rev)** of the output shaft (≈1 count/degree).




The NXT motor’s integrated gearbox and encoder made it an attractive choice: robust, self-contained, and reliable. Feedback enables precise traction control (speed regulation, slip detection, accurate distance moves).

**Important note:** Running above nominal voltage (11.1 V vs 9 V) was tested carefully. Typical draw **0.2–0.6 A**, spikes up to **~2 A** on acceleration or stall. The DRV8871 driver and battery can handle these spikes. Continuous stalling at 11.1 V is avoided to prevent overheating; in practice the motor remained within safe temperature limits due to short duty cycles and driver current limiting.

---

## 5) Power Electronics

### DRV8871 Motor Driver (for Traction Motor)

The **DRV8871** is a compact single-channel DC motor driver module powering the NXT traction motor directly from the battery’s **11.1 V** line. It was selected because:

* Wide voltage range (up to **45 V**) and **3.6 A peak**, covering the motor’s needs with margin.
* Built-in protections: **UVLO**, **OCP**, and **TSD**.
* Very compact and light; can be mounted near the motor to minimize high-current wire length.



Controlled by the Arduino Nano (PWM for speed + DIR for polarity). The driver’s **current limiting** protects motor and battery without external fuses/sensors. Proximal mounting reduces voltage drop and EMI.

---

### Mini360 Buck Converters (Regulators) + Output Filtering

The **Mini360** buck converters (MP2307) create the needed rails from **11.1 V LiPo**:

* **5.2 V** for Raspberry Pi 5, Arduino Nano, and 5 V peripherals (USB camera).
* **6.0 V** dedicated to the MG995 steering servo.
* **11.1 V direct** serves the DRV8871 (traction).



These modules are ~17×11 mm, efficient (~95%), and handle ≈1.8 A continuous. The 5.2 V line is chosen to ensure the Pi sees ≥5.0 V at load. The **6.0 V** servo rail has a **47 µF** electrolytic capacitor **at the output** for local smoothing (eliminated resets/glitches).



**Mounting:** Inline with the harness, soldered and heat-shrunk. This reduces rail length, saves space/weight, and keeps regulators close to loads.

---

### Ovonic 3S 11.1 V 5200 mAh LiPo Battery

The **Ovonic 3S 11.1 V 5200 mAh** LiPo is the main energy source, selected for:

* **High capacity (5200 mAh)** → ample runtime across rounds and development.
* **High discharge capability** → handles motor/servo spikes with low sag.
* **Stable voltage curve** (~12.6 V full → ~11.1 V nominal → ~9.6 V near empty).



Battery connects to a master **power switch**. 

---

## 6) Power Topology



* The main power switch controls the entire power distribution; when ON, **11.1 V** feeds the bus; buck converters derive **5.2 V** and **6.0 V** rails.
* Independently regulated rails greatly improve stability (noisy/high-current loads are separated from sensitive logic).
* **47 µF** on the servo’s **6 V** rail filters transients.
* **Star grounding**: all returns converge at a single node near battery negative; minimizes loops/ground-bounce.
* Modular distribution eases isolation and diagnostics.

---

## 7) Signal Integrity & EMI Practices

Several best practices were implemented to ensure signal integrity and reduce electromagnetic interference (EMI):

* **Power Domain Isolation:** Logic (Pi, Nano, camera) on 5.2 V; servo on its own 6.0 V; drive motor on 11.1 V.
* **Local Decoupling Capacitors:** 47 µF on the 6 V servo line; standard decoupling present on Pi/Nano inputs.
* **Star Grounding:** Single-point ground node.
* **Short, Bundled Wiring:** Short runs, careful routing, twisted pairs where beneficial.
* **Proper Signal Leveling:** Pi (3.3 V) ↔ Nano (5 V) UART link operates reliably at short distance; future designs may use a level shifter or 3.3 V MCU.

**Result:** The combination of isolated rails and filtering eliminated early resets and noise issues; communications and sensing remain stable during operation.

---

## 8) Operating Procedure

**Power-on:**

1. Verify main power **OFF**; check connections and polarity.
2. Connect LiPo.
3. Switch main power **ON** (5.2/6.0 V rails energize; Pi boots; Nano starts).
4. Wait for Pi boot.

**Pre-run checks:**

* **Steering test:** center linkage; command servo lock-to-lock; observe smooth behavior, no resets.
* **Drive test (wheel lifted):** command small motion; check DRV8871 temperature and battery sag.
* **Encoder feedback:** spin wheel by hand; verify counts and direction.
* **Communication:** verify UART roundtrip.

**Run (during operation):**

* Start main control program on the Pi; observe steering and throttle responses; monitor battery voltage; use main power switch for emergency stop if needed.

**Shutdown:**

1. Stop the program; ideally issue OS shutdown on Pi.
2. Toggle main power **OFF**.
3. Disconnect battery for storage; store LiPo at safe voltage.
4. Inspect for heat/loose wires.

---

## 9) Protection & Safety Measures

* **Battery Monitoring:** Nano reads LiPo voltage; warns on low level.
* **Current Limiting (DRV8871):** Protects motor/battery from overload.
* **Independent Servo Rail:** Servo surges do not brown-out logic.
* **Star Ground & Decoupling:** Reduces erratic behavior from noise.
* **Main Kill Switch:** Fast global cut-off (fuse considered for future).
* **Thermal Considerations:** DRV8871 and Mini360 verified within normal temperature rise; Pi 5 uses a small heatsink.

---

## 10) Power Budget

Below is a summary of the power budget for the robot, listing each major component, its supply voltage, typical current draw, peak current draw, and any relevant notes:

| Component | Voltage | Avg Current (A) | Peak Current (A) | Notes |
| --- | ---: | ---: | ---: | --- |
| Raspberry Pi 5  | 5.2 V | ~1.0 | 2–3 | Main processor (vision & navigation logic). Higher peaks if CPU/GPU fully used. |
| Arduino Nano | 5.2 V | ~0.05 | ~0.05 | Auxiliary microcontroller (nearly negligible draw). |
| UVC Camera | 5.2 V | ~0.05 | ~0.05 | Innomaker wide-angle camera (low-power device). |
| MG995 Servo | 6.0 V | 0.1–0.3* | ~2.0 | Steering servo. Avg depends on motion load; idle ~0.1 A, active ~0.3–0.5 A. |
| NXT Drive Motor |  11.1 V | 0.2–0.6 | ~2.0 | Traction motor; peaks on acceleration or stall. |
| DRV8871 Driver  |  11.1 V | <0.01 | (self-limit) | Quiescent very low; limits motor current ~3.6 A max. |
| Ovonic 3S LiPo  |  11.1 V | — | — | Battery can supply >100 A bursts if shorted; our usage peaks <~5 A. 5200 mAh capacity. |

* The servo’s “Avg Current” varies widely based on usage; ~0.1–0.3 A is a mid-range estimate.

From the above, **typical total draw ≈ 2–3 A average** (battery side; note conversion efficiencies). Plenty of headroom for regulators and wiring.

**Illustrative current distribution (approximate):**

```mermaid
pie title Avg Current Share by Component (estimated)
  "Raspberry Pi 5 (~1.0 A @ 5.2 V)" : 1.0
  "Arduino + Camera (~0.10 A @ 5.2 V)" : 0.10
  "MG995 Servo (active ~0.30 A @ 6 V)" : 0.30
  "NXT Motor (drive ~0.60 A @ 11.1 V)" : 0.60
```

Sizing checks:

* **5.2 V** regulator ≈1.1 A typical (Pi+Nano+camera) → within ~1.5–2 A capacity.
* **6.0 V** regulator (servo) → avg few hundred mA, tolerates 1–2 A bursts with local cap.
* Battery and wiring/connectors (>10 A rated) → ample margin.

---

## 11) Conclusion

The electrical system of **Team Rulo Bot** has been carefully designed and refined to maximize performance, stability, and noise immunity, which are all crucial for a successful autonomous robot in competition:

* The **Raspberry Pi 5** serves as a powerful central processor, handling demanding real-time vision tasks and high-level decision making.
* The **Arduino Nano** provides fast, deterministic control of hardware (sensors and actuators) and safeguards the system with low-level monitoring, creating a robust two-layer control scheme.
* The **Innomaker UVC camera** offers wide-angle vision, allowing the robot to perceive its environment fully using vision alone, simplifying the sensor suite and focusing efforts on camera-based algorithms.
* The **MG995 servo** and **NXT motor** (driven by the DRV8871) together deliver responsive steering and reliable drive power. Their dedicated power supplies and feedback mechanisms (encoder for the motor) mean the robot can maneuver precisely and with confidence in its movements.
* The power distribution (via **Mini360 buck converters** and a high-capacity **LiPo** battery) provides clean and adequate power to all components.
* Critical issues encountered early, such as voltage dips from the servo causing resets, were solved by hardware fixes (like the addition of the **47 µF** capacitor and isolating the servo’s supply).
* The result is a system that can operate under competition stress — rapid movements, continuous vision processing, and potential electrical noise — without compromising reliability or performance.

In summary, the electrical and electronic design is **optimized for competition use**, emphasizing **reliability, safety, and ease of maintenance**. The separation of concerns (power and control), along with thoughtful integration of components, provides a strong foundation for **WRO Future Engineers 2025** and beyond.

---

## 12) References

* **Tower Pro MG995 Datasheet** — sandorobotics.com.mx
* **DRV8871 Motor Driver – TI (Texas Instruments) datasheet** — ti.com
* **LEGO NXT Motor (9842) Reference** — lagos.udg.mx
* **Mini360 Buck Converter (MP2307)** — components101.com
* **Raspberry Pi (Power Requirements and Best Practices)** — forums.raspberrypi.com
* **UVC Camera Module Specs (Innomaker)** — spanish.module-camera.com
* **Ovonic LiPo Battery (11.1 V 5200 mAh)** — dynamoelectronics.com

---

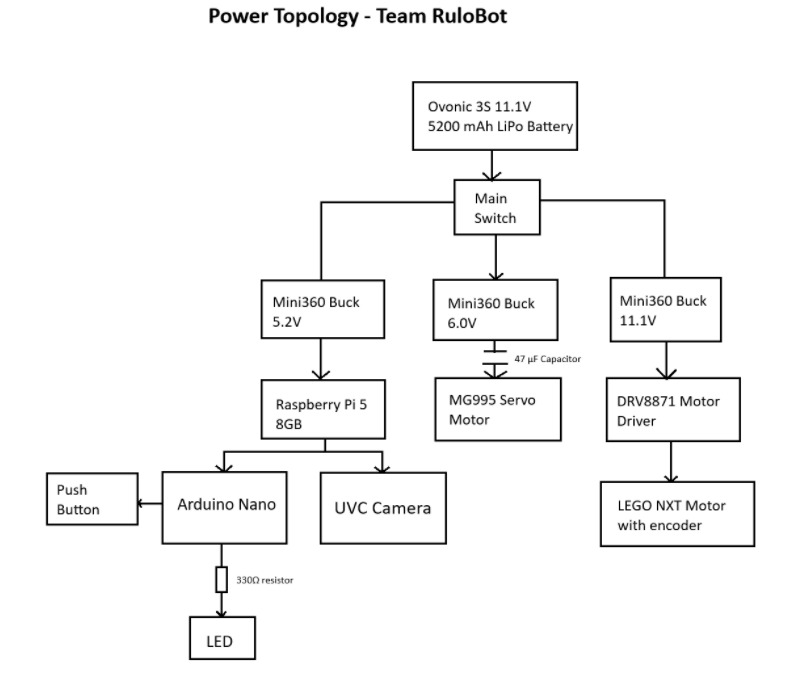
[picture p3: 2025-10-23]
Technical_Reports/Electrical and Electronic report/RuloBot power topology.jpg

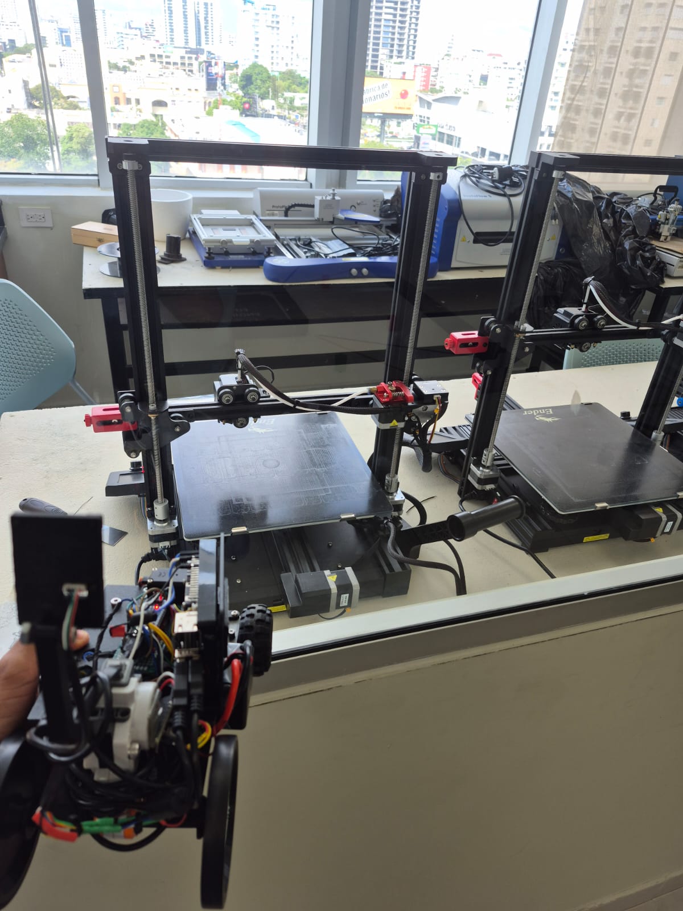
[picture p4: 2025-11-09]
Robot_photos/Imagen de WhatsApp 2025-11-01 a las 14.22.48_2016ab30.jpg

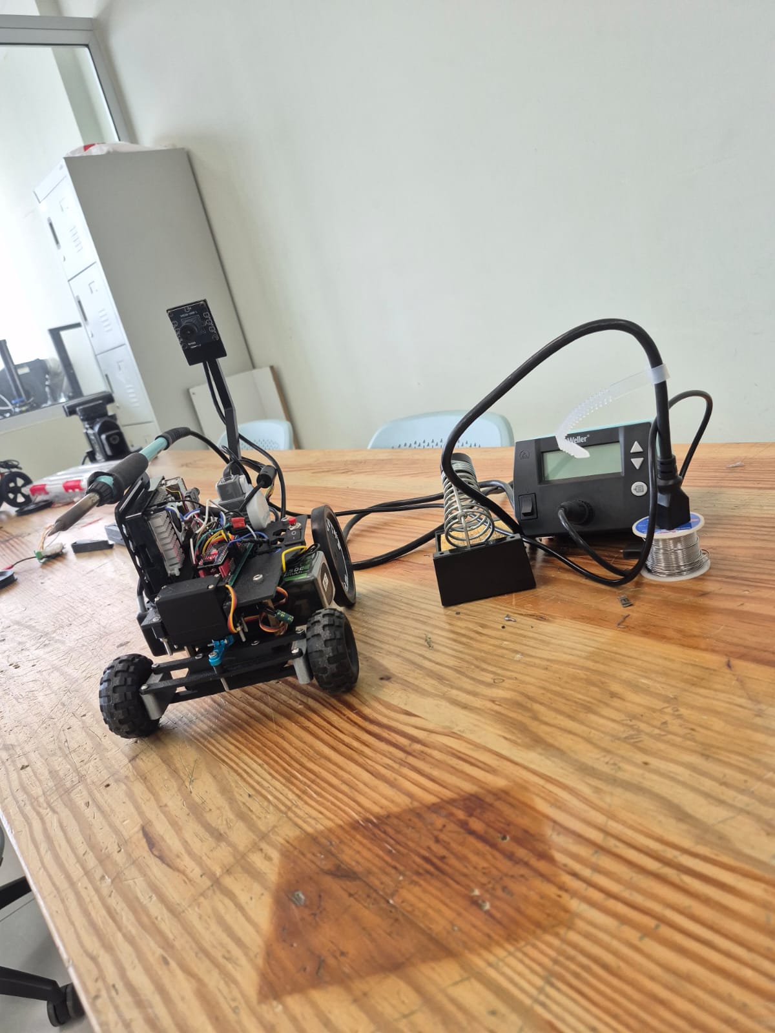
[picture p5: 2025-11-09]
Robot_photos/Imagen de WhatsApp 2025-11-01 a las 14.22.49_93e5cfcd.jpg

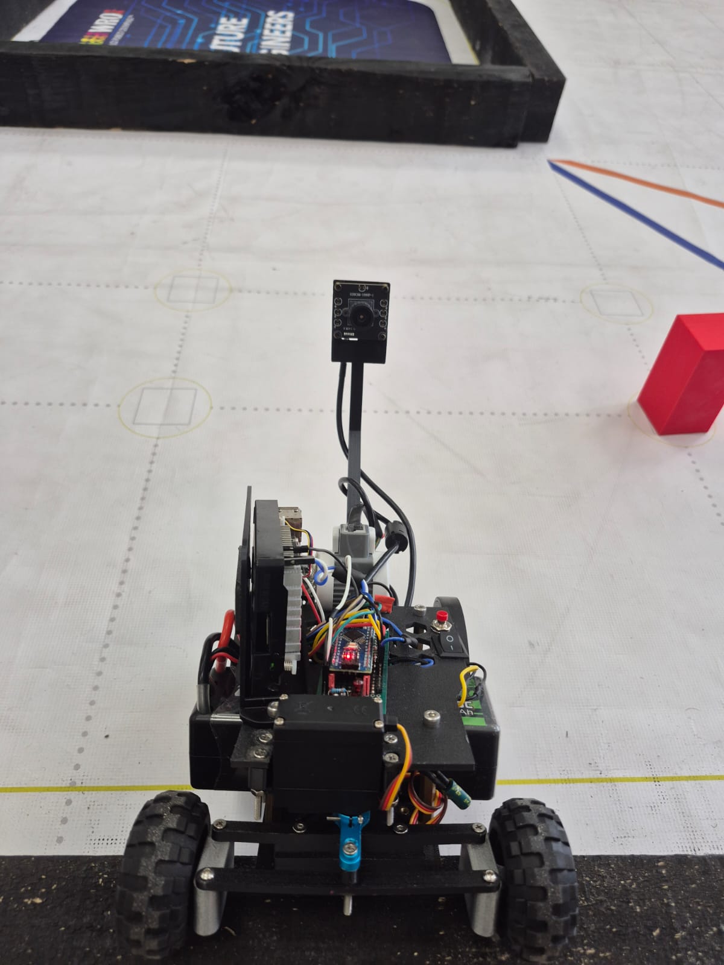
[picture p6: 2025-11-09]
Robot_photos/Imagen de WhatsApp 2025-11-01 a las 14.22.49_1816b7df.jpg

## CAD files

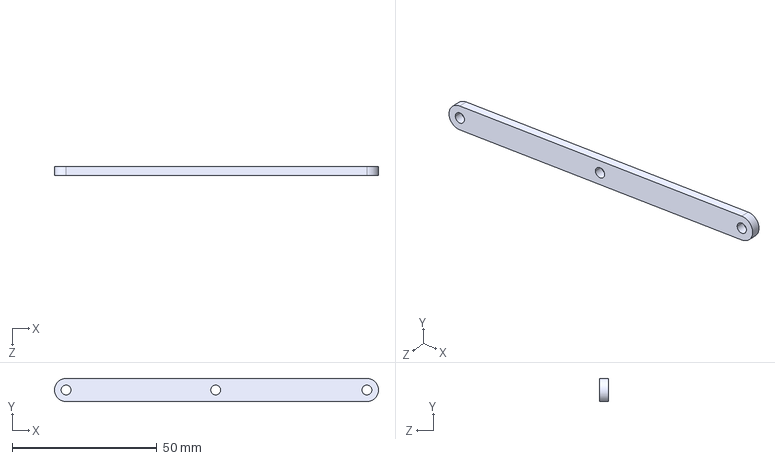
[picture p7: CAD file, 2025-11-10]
3D_Models/current_models/step/Movable_Assembly.STEP
111.9 x 8.00 x 3.00 mm

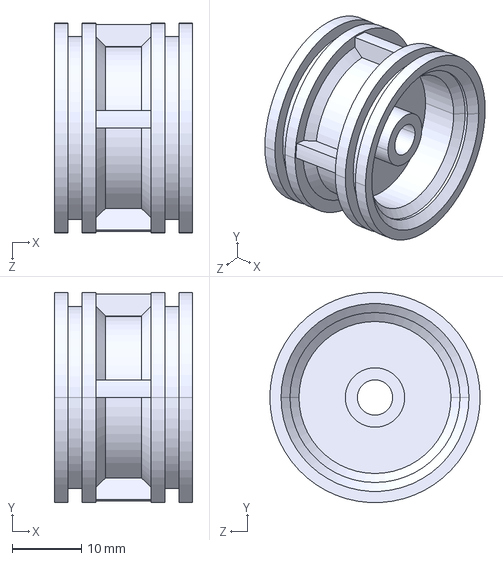
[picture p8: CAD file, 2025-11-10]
3D_Models/current_models/step/Front_Wheel_Hub.STEP
20.0 x 30.4 x 30.4 mm

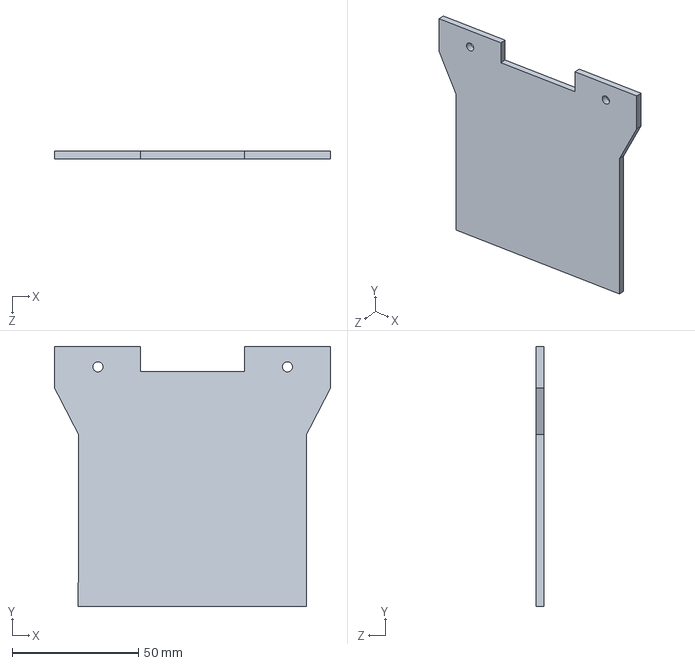
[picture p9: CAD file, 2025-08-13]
upper base 0.1.SLDPRT
109.2 x 103.0 x 3.00 mm

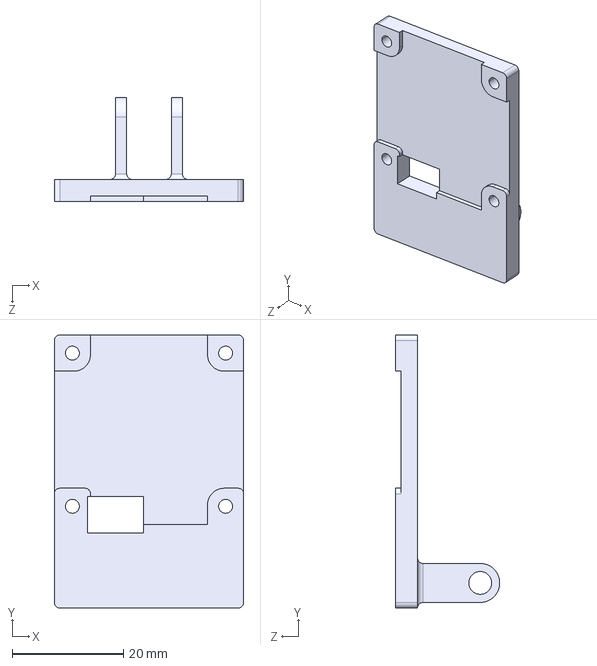
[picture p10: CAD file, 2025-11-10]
3D_Models/current_models/step/Camera_Rotating_Mount.STEP
34.0 x 49.0 x 18.8 mm

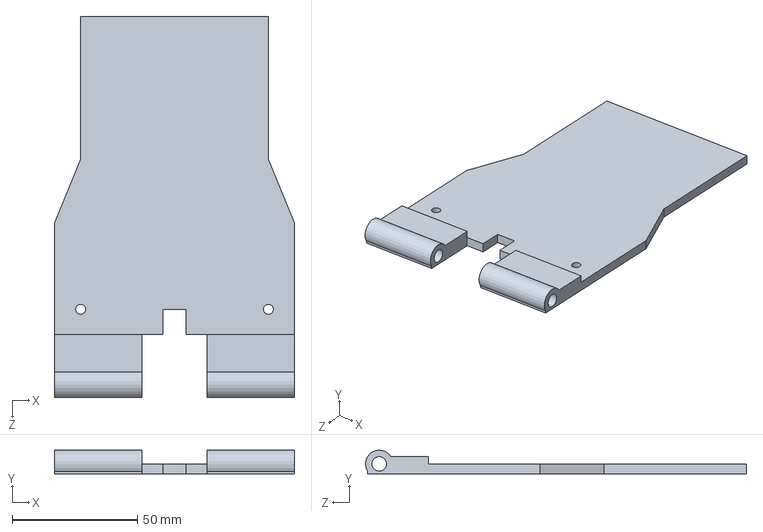
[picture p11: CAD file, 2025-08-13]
lower base 0.1.SLDPRT
96.0 x 9.49 x 152.2 mm

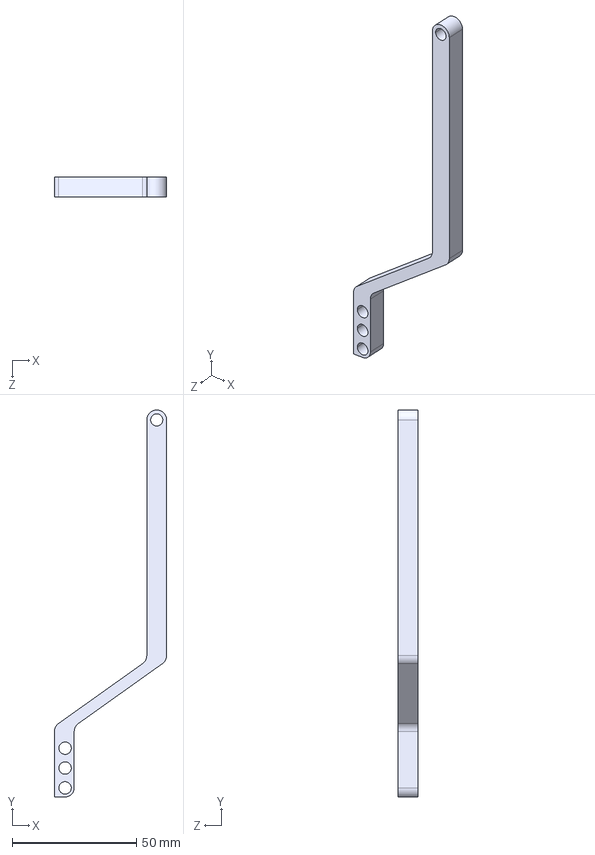
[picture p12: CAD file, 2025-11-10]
3D_Models/current_models/step/Camera_stick.STEP
45.2 x 156.0 x 8.00 mm

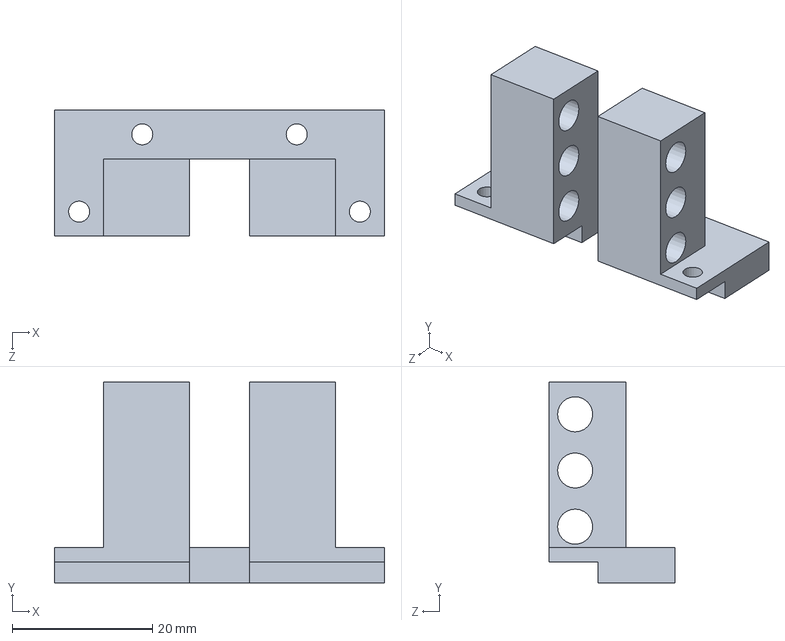
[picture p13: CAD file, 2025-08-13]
Motor mount 0.1.SLDPRT
47.0 x 28.6 x 18.0 mm

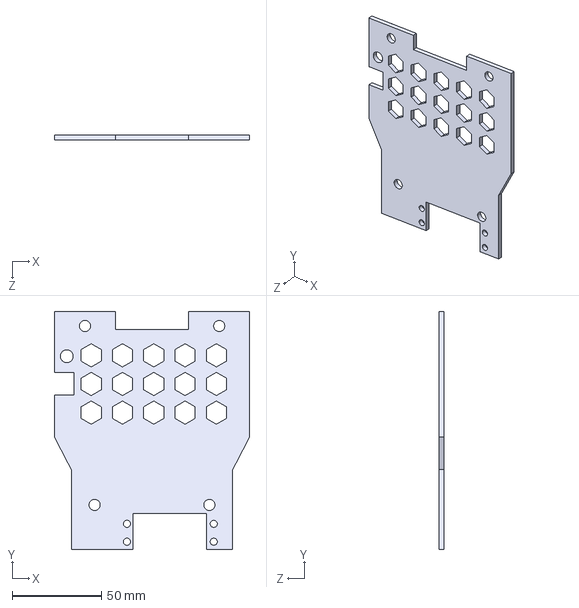
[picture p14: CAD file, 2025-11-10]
3D_Models/current_models/step/Upper_Base.STEP
109.2 x 133.0 x 3.00 mm

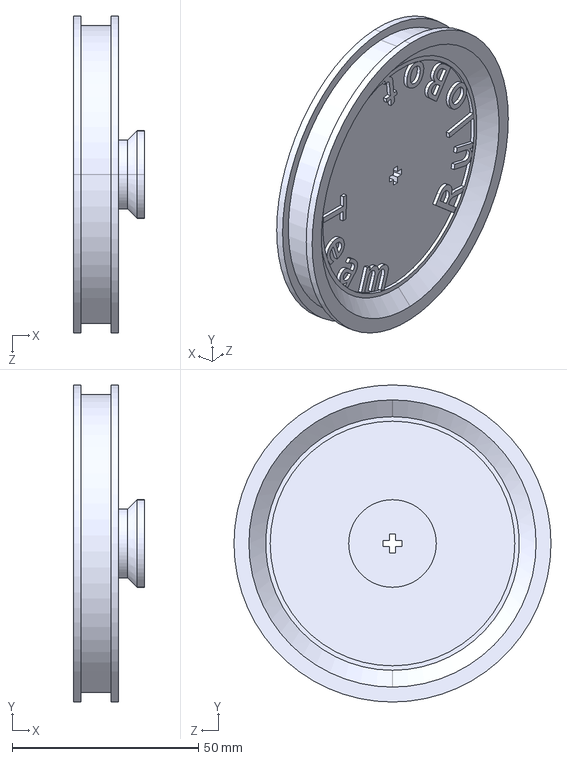
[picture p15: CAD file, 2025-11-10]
3D_Models/current_models/step/Rear_Wheel_Hub.STEP
19.0 x 85.0 x 85.0 mm

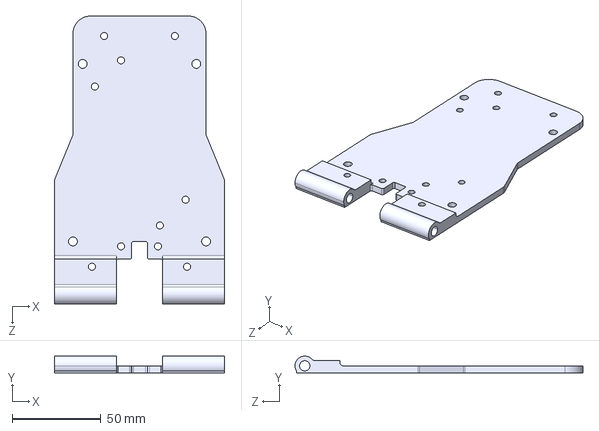
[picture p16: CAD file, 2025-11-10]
3D_Models/current_models/step/Base.STEP
96.0 x 9.50 x 162.3 mm

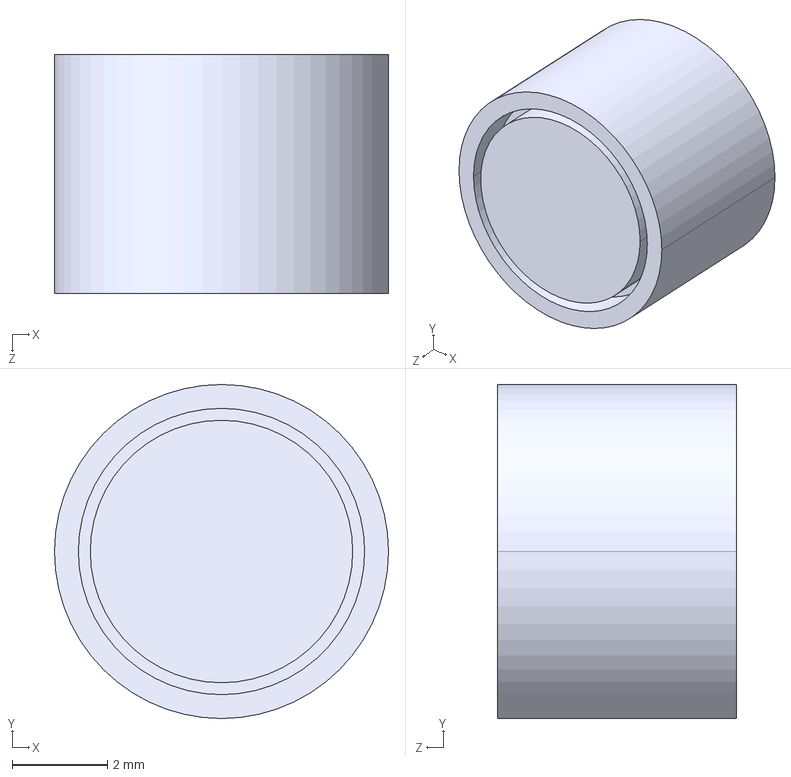
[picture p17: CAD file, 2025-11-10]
3D_Models/current_models/step/Stopper.STEP
7.00 x 7.00 x 5.00 mm

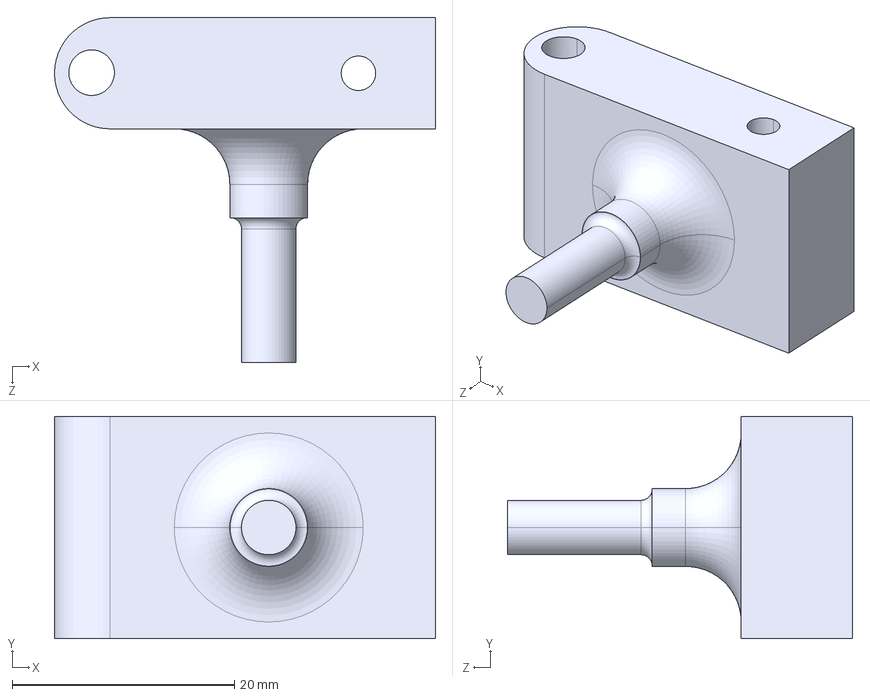
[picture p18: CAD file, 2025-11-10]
3D_Models/current_models/step/Drive_Wheel_Support.STEP
34.3 x 20.0 x 31.0 mm

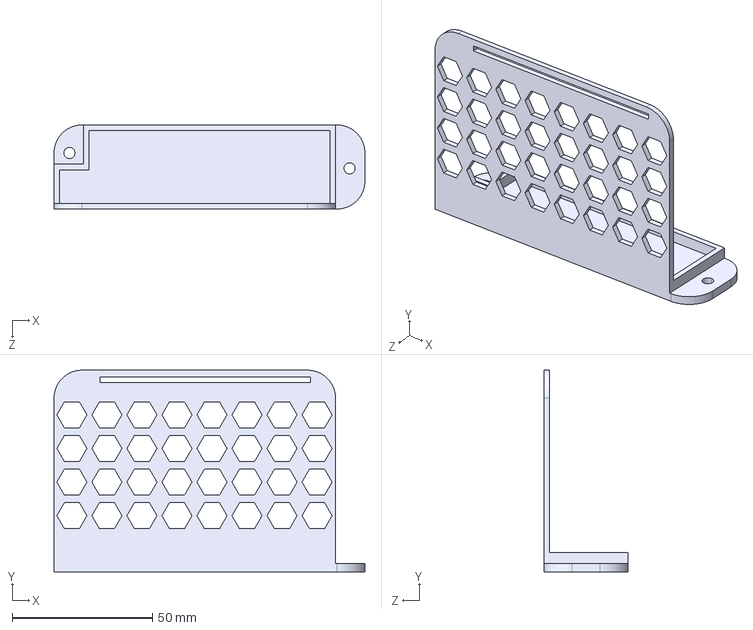
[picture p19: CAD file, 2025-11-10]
3D_Models/current_models/step/Raspberry_Base.STEP
111.0 x 72.0 x 30.0 mm

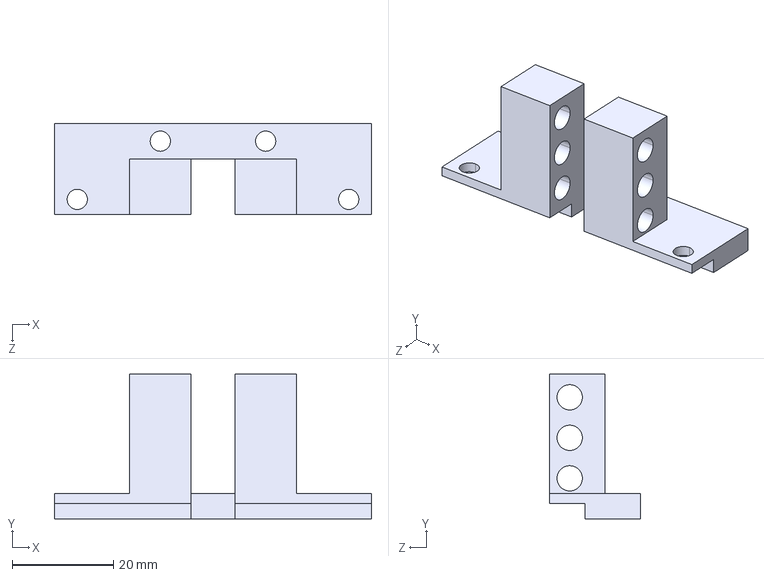
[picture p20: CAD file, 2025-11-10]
3D_Models/current_models/step/Motor_Mount.STEP
62.6 x 28.6 x 18.0 mm

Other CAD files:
3D_Models/current_models/step/Raspberry_Pi_holder.STEP
3D_Models/current_models/step/Chassis_Joint.STEP
3D_Models/current_models/step/Servo_Connector.STEP
3D_Models/current_models/step/Label_Plate.STEP
3D_Models/current_models/step/Gyro_support_Bracket.STEP
3D_Models/current_models/step/Servo_Screw_Mount.STEP
3D_Models/current_models/stl/Base.STL
3D_Models/current_models/stl/Camera_Rotating_Mount.STL
3D_Models/current_models/stl/Camera_stick.STL
3D_Models/current_models/stl/Chassis_Joint.STL
3D_Models/current_models/stl/Drive_Wheel_Support.STL
3D_Models/current_models/stl/Front_Wheel_Hub.STL
3D_Models/current_models/stl/Gyro_support_Bracket.STL
3D_Models/current_models/stl/Label_Plate.STL
3D_Models/current_models/stl/Motor_Mount.STL
3D_Models/current_models/stl/Movable_Assembly.STL
3D_Models/current_models/stl/Raspberry_Base.STL
3D_Models/current_models/stl/Raspberry_Pi_holder.STL
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

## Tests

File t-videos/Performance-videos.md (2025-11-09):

Performance Videos — Team Rulo Bot Testing Sessions
AUTONOMOUS ROBOT TEST – Forward and Reverse Motion

https://youtube.com/shorts/DLdXPhjLxYY

In this test, we were verifying the behavior of the traction system using the LEGO NXT 9842 motor and the DRV8871 driver.
The goal was to confirm that the robot could move forward and backward smoothly under PWM control, maintaining stable direction changes without losing alignment or causing mechanical vibration.

AUTONOMOUS ROBOT TEST – Vision Test: Red and Green Color Detection

https://youtu.be/MnDNOvI_E2s

During this test, we were calibrating the color detection system of the provisional camera.
We focused on adjusting the HSV and LAB masks in OpenCV to correctly identify red and green pillars, which are essential for obstacle decision-making during the Obstacle Challenge.

TEST – Forward and Backward

https://www.youtube.com/shorts/6pMi8gZCbPo

In this experiment, we were testing the encoder’s response and traction symmetry by moving the robot back and forth multiple times.
The purpose was to verify that both acceleration and braking were consistent, and that the robot maintained linear stability when changing direction.

OPEN CHALLENGE – Clockwise Run

https://www.youtube.com/watch?v=ao2uUjXZPo4

Here we were performing one of the first complete runs of the Open Challenge in the clockwise direction.
We tested PD steering tuning, lane centering using the front ROI, and overall stability during continuous lap navigation around the playfield.

OPEN CHALLENGE – Counterclockwise Run

https://www.youtube.com/watch?v=F6bJ-BMMgI8

This session was focused on validating the same Open Challenge run but in the counterclockwise direction.
We were confirming that the PD control, ROI detection, and camera calibration worked equally well in both orientations, ensuring symmetrical performance and algorithm consistency.

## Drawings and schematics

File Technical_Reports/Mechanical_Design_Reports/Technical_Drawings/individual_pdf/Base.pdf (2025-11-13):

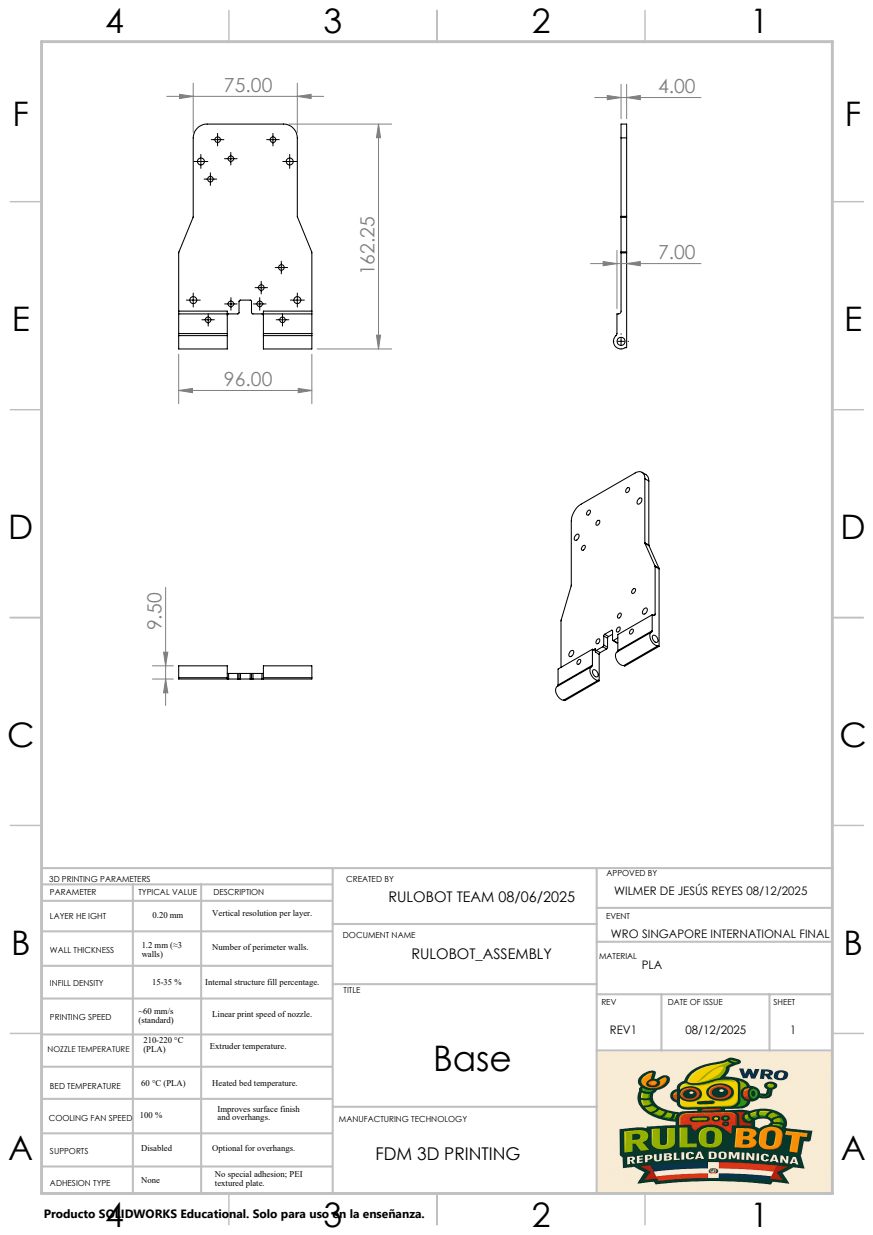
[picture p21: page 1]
DOCUMENT NAME; MANUFACTURING TECHNOLOGY FDM 3D PRINTING

3D PRINTING PARAMETERS | CREATED BY RULOBOT TEAM 08/06/2025 | APPOVED BY WILMER DE JESÚS REYES 08/12/2025
PARAMETER | TYPICAL VALUE | DESCRIPTION

LAYER HE IGHT | 0.20 mm | Vertical resolution per layer.

EVENT
WRO SINGAPORE INTERNATIONAL FINAL

WALL THICKNESS | 1.2 mm (≈3 walls) | Number of perimeter walls.

INFILL DENSITY | 15-35 % | Internal structure fill percentage.

REV REV1 | DATE OF ISSUE 08/12/2025 | SHEET 1

PRINTING SPEED | ~60 mm/s (standard) | Linear print speed of nozzle.

NOZZLE TEMPERATURE | 210-220 °C (PLA) | Extruder temperature.

BED TEMPERATURE | 60 °C (PLA) | Heated bed temperature.

COOLING FAN SPEED | 100 % | Improves surface finish and overhangs.

Producto SOLIDWORKS Educational. Solo para uso en la enseñanza.

SUPPORTS | Disabled | Optional for overhangs.

ADHESION TYPE | None | No special adhesion; PEI textured plate.

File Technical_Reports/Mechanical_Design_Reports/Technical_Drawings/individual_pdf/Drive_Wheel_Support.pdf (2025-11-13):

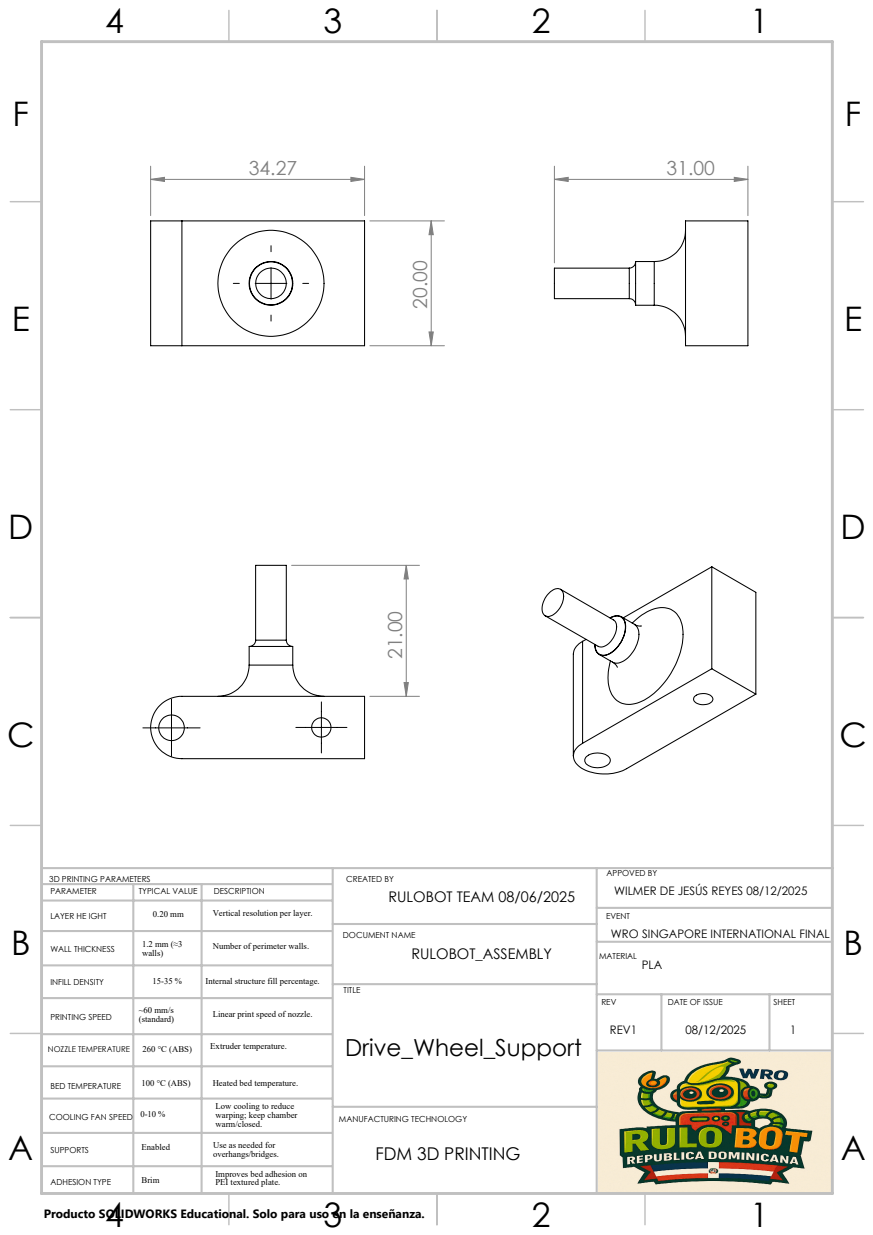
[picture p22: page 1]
DOCUMENT NAME; MANUFACTURING TECHNOLOGY FDM 3D PRINTING

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

EVENT
WRO SINGAPORE INTERNATIONAL FINAL

WALL THICKNESS | 1.2 mm (≈3 walls) | Number of perimeter walls.

INFILL DENSITY | 15-35 % | Internal structure fill percentage.

PRINTING SPEED | ~60 mm/s (standard) | Linear print speed of nozzle. | REV REV1 | DATE OF ISSUE 08/12/2025 | SHEET 1

NOZZLE TEMPERATURE | 260 °C (ABS) | Extruder temperature.

BED TEMPERATURE | 100 °C (ABS) | Heated bed temperature.

COOLING FAN SPEED | 0-10 % | Low cooling to reduce warping; keep chamber warm/closed.

Producto SOLIDWORKS Educational. Solo para uso en la enseñanza.

SUPPORTS | Enabled | Use as needed for overhangs/bridges.

ADHESION TYPE | Brim | Improves bed adhesion on PEI textured plate.

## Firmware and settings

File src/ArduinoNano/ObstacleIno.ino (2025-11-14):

// ============================================================================
// Team Rulo Bot — Park Exit por Encoder -> luego Modo Obstacle (unificado)
// HW: Nano + DRV8871 (IN1=6=REV, IN2=5=FWD), Servo MG995 (D4), LED D10,
//     Botón D2 (a GND, INPUT_PULLUP), Encoder canal A en D3 (INT1).
// Baud: 115200
// ============================================================================

#include <Arduino.h>
#include <Servo.h>
#include <math.h> // roundf()

// ---------------- Pins ----------------
#define MOTOR_IN1    6     // DRV8871 IN1 -> REV (PWM)
#define MOTOR_IN2    5     // DRV8871 IN2 -> FWD (PWM)
#define SERVO_PIN    4     // MG995
#define LED_PIN      10
#define BUTTON_PIN   2     // Push-button a GND (INPUT_PULLUP)
#define ENC_A_PIN    3     // Encoder canal A (INT1)

// ------------- Servo -------------
const int SERVO_CENTER = 84;
const int SERVO_LEFT   = 30;   // extremo IZQ (validado)
const int SERVO_RIGHT  = 138;  // extremo DER (validado)

// ========= Objetos/estado que deben existir ANTES de usarse =========
Servo sv;

enum RunMode {WAIT_BUTTON_EXIT, EXIT_RUNNING, OBSTACLE_RUNNING};
RunMode mode = WAIT_BUTTON_EXIT;

// ========= Prototipos (opcional, pero útil si mueves cosas) =========
void serialPump();
void steerAngle(int ang);

// ================= PARÁMETROS AJUSTABLES =================
// ---- EXIT por encoder ----
int   EXTREME_ANGLE       = SERVO_LEFT; // Se ajusta por Serial con EXT:LEFT/RIGHT

float FWD1_DIST_CM        = 8.0;
float REV1_DIST_CM        = 5.0;
float FWD2_DIST_CM        = 6.7;
float REV2_DIST_CM        = 3.0;
float FWD3_DIST_CM        = 17.0;

int   SPEED_FWD           = 170;
int   SPEED_REV           = 150;

int   PWM_BRAKE           = 180;
int   BRAKE_BURST_MS      = 50;
int   COAST_MS            = 40;
int   DWELL_MS            = 800;

int   EXTREME_WAIT_MS     = 1000;
int   SERVO_SETTLE_MS     = 200;
int   CENTER_SETTLE_MS    = 150;

int   PWM_KICK            = 230;  // ayuda a romper fricción en REV
int   KICK_MS             = 60;

// ---- Obstacle (fase 2) ----
int   OBST_SPEED_FWD      = 200;  // avance constante en obstacle
int   OBST_SPEED_REV      = 150;  // REV segura para comando REV
int   OBST_REV_DEFAULT_MS = 450;  // si no se especifica en REV:ms

// Encoder / rueda
const float WHEEL_DIAMETER_MM = 56.0f; // rueda trasera actual
const long  TICKS_PER_REV     = 180;
// =========================================================

// ========= Estado encoder =========
volatile unsigned long enc_count = 0;
void enc_isr(){ enc_count++; }

// ========= Utils motor/servo =========
inline void motorCoast(){ analogWrite(MOTOR_IN1,0); analogWrite(MOTOR_IN2,0); }
inline void motorFwdPWM(int pwm){ pwm=constrain(pwm,0,255); analogWrite(MOTOR_IN1,0);   analogWrite(MOTOR_IN2,pwm); }
inline void motorRevPWM(int pwm){ pwm=constrain(pwm,0,255); analogWrite(MOTOR_IN1,pwm); analogWrite(MOTOR_IN2,0);  }

void hardBrakeFromFWD(){
  motorRevPWM(PWM_BRAKE);
  unsigned long t0=millis();
  while(millis()-t0 < (unsigned long)BRAKE_BURST_MS){
    if (digitalRead(BUTTON_PIN)==LOW) break;
  }
  motorCoast(); delay(COAST_MS);
}

void hardBrakeFromREV(){
  motorFwdPWM(PWM_BRAKE);
  unsigned long t0=millis();
  while(millis()-t0 < (unsigned long)BRAKE_BURST_MS){
    if (digitalRead(BUTTON_PIN)==LOW) break;
  }
  motorCoast(); delay(COAST_MS);
}

void steerAngle(int ang){
  ang = constrain(ang, SERVO_LEFT, SERVO_RIGHT);
  sv.write(ang);
}

void waitButtonPressRelease(){
  while (digitalRead(BUTTON_PIN) != LOW) { serialPump(); } // permitir EXT:* antes
  delay(20);
  while (digitalRead(BUTTON_PIN) == LOW) { serialPump(); }
  delay(20);
}

bool emergencyStopIfPressed(){
  if (digitalRead(BUTTON_PIN)==LOW){
    motorCoast();
    return true;
  }
  return false;
}

// Encoder: cm -> ticks
unsigned long ticksForDistanceCm(float cm){
  float perim_mm = 3.14159265f * WHEEL_DIAMETER_MM;
  float dist_mm  = cm * 10.0f;
  float revs     = dist_mm / perim_mm;
  unsigned long ticks = (unsigned long) roundf(revs * (float)TICKS_PER_REV);
  return (ticks>0 ? ticks : 1);
}

// Mover por distancia usando encoder
bool moveDistanceCm(float cm, int dir, int pwm, bool kick){
  unsigned long target = ticksForDistanceCm(cm);
  noInterrupts(); enc_count = 0; interrupts();

  if (dir > 0){
    motorFwdPWM(pwm);
  } else {
    if (kick){ motorRevPWM(PWM_KICK); delay(KICK_MS); }
    motorRevPWM(pwm);
  }

  unsigned long wd = millis();
  while (enc_count < target){
    if (emergencyStopIfPressed()) { motorCoast(); return false; }
    if (millis() - wd > 7000UL) {
      Serial.println(F("[WARN] Watchdog — abort tramo"));
      motorCoast(); return false;
    }
  }
  motorCoast();
  return true;
}

// ========= Serial parser =========
String rxLine;

void handleCommand(const String& s){
  if (s.startsWith("EXT:")){
    if (s.endsWith("LEFT")){
      EXTREME_ANGLE = SERVO_LEFT;
      Serial.println(F("[EXT] LEFT seleccionado"));
    } else if (s.endsWith("RIGHT")){
      EXTREME_ANGLE = SERVO_RIGHT;
      Serial.println(F("[EXT] RIGHT seleccionado"));
    }
  } else if (s == "EXT?"){
    Serial.print(F("[EXT] actual = ")); Serial.println(EXTREME_ANGLE);
  }
  // En modo Obstacle, también aceptamos control:
  else if (mode==OBSTACLE_RUNNING){
    if (s.startsWith("STEER:")){
      int ang = s.substring(6).toInt();
      steerAngle(ang);
    } else if (s=="TURN_ON"){
      digitalWrite(LED_PIN, HIGH);
    } else if (s=="TURN_OFF"){
      digitalWrite(LED_PIN, LOW);
    } else if (s=="STOP"){
      motorCoast(); steerAngle(SERVO_CENTER);
    } else if (s.startsWith("REV")){
      int ms = OBST_REV_DEFAULT_MS;
      int idx = s.indexOf(':');
      if (idx>0){ int v = s.substring(idx+1).toInt(); if (v>0) ms=v; }
      // REV segura con servo al centro:
      steerAngle(SERVO_CENTER);
      motorRevPWM(OBST_SPEED_REV);
      unsigned long t0=millis();
      while((int)(millis()-t0) < ms){}
      motorFwdPWM(OBST_SPEED_FWD);
    }
  }
}

void serialPump(){
  while (Serial.available()){
    char c = (char)Serial.read();
    if (c=='\n' || c=='\r'){
      if (rxLine.length()>0){ handleCommand(rxLine); rxLine=""; }
    } else {
      if (rxLine.length()<80) rxLine += c;
    }
  }
}

void setup(){
  Serial.begin(115200);
  pinMode(MOTOR_IN1,OUTPUT);
  pinMode(MOTOR_IN2,OUTPUT);
  pinMode(LED_PIN,OUTPUT);
  pinMode(BUTTON_PIN,INPUT_PULLUP);
  pinMode(ENC_A_PIN,INPUT_PULLUP);

  attachInterrupt(digitalPinToInterrupt(ENC_A_PIN), enc_isr, RISING);

  sv.attach(SERVO_PIN);
  steerAngle(SERVO_CENTER);
  motorCoast();
  digitalWrite(LED_PIN, LOW);

  Serial.println(F("Unificado: Park Exit -> Obstacle. Acepte EXT:LEFT/RIGHT por Serial."));
  Serial.print (F("DIAM(mm)=")); Serial.print(WHEEL_DIAMETER_MM);
  Serial.print (F("  TICKS/REV=")); Serial.println(TICKS_PER_REV);
  Serial.println(F("Pulse el botón para ejecutar la salida por encoder."));
}

void loop(){
  serialPump();

  if (mode==WAIT_BUTTON_EXIT){
    // Espera botón para iniciar la secuencia de salida
    waitButtonPressRelease();
    digitalWrite(LED_PIN, HIGH);
    Serial.println(F("[SEQ] START (Exit)"));
    mode = EXIT_RUNNING;

    // ===== Secuencia por encoder (+REV2/FWD3) =====
    steerAngle(EXTREME_ANGLE);
    delay(EXTREME_WAIT_MS);

    if (!moveDistanceCm(FWD1_DIST_CM, +1, SPEED_FWD, false)) goto end_exit;
    hardBrakeFromFWD(); delay(DWELL_MS);

    steerAngle(SERVO_CENTER); delay(CENTER_SETTLE_MS);
    if (!moveDistanceCm(REV1_DIST_CM, -1, SPEED_REV, true)) goto end_exit;
    hardBrakeFromREV(); delay(DWELL_MS);

    steerAngle(EXTREME_ANGLE); delay(SERVO_SETTLE_MS);
    if (!moveDistanceCm(FWD2_DIST_CM, +1, SPEED_FWD, false)) goto end_exit;
    hardBrakeFromFWD(); delay(DWELL_MS);

    steerAngle(SERVO_CENTER); delay(CENTER_SETTLE_MS);
    if (!moveDistanceCm(REV2_DIST_CM, -1, SPEED_REV, true)) goto end_exit;
    hardBrakeFromREV(); delay(DWELL_MS);

    steerAngle(EXTREME_ANGLE); delay(SERVO_SETTLE_MS);
    if (!moveDistanceCm(FWD3_DIST_CM, +1, SPEED_FWD, false)) goto end_exit;
    hardBrakeFromFWD();

  end_exit:
    motorCoast();
    steerAngle(SERVO_CENTER);
    digitalWrite(LED_PIN, LOW);
    Serial.println(F("[SEQ] END"));     // <- la Pi espera esto para pasar a Obstacle
    delay(1000);                        // 1 s antes de Obstacle
    // ===== Entrar a modo Obstacle =====
    motorFwdPWM(OBST_SPEED_FWD);
    mode = OBSTACLE_RUNNING;
    Serial.println(F("[OBST] RUNNING — listo para STEER:/TURN_ON/OFF/STOP/REV"));

  } else if (mode==OBSTACLE_RUNNING){
    // Mantener avance; control por Serial en handleCommand()
    if (digitalRead(BUTTON_PIN)==LOW){
      motorCoast(); steerAngle(SERVO_CENTER); digitalWrite(LED_PIN, LOW);
      while (digitalRead(BUTTON_PIN)==LOW){} delay(20);
      mode = WAIT_BUTTON_EXIT;
      Serial.println(F("[OBST] STOP by button — regreso a espera de salida."));
    }
  }
}

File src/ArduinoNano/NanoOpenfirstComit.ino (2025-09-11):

// === Team Rulo Bot — Nano (GO button D2) ===
// Simple & stable: Forward always + TURN_[R/L](90°) by ENCODER + NUDGE
// - Sin heartbeat, sin watchdog, sin centrados extra ni lógica de parada automática.
// - STOP solo si llega el comando explícito por serie.
// - AL RECIBIR STOP: avanzar 30 cm y frenar.  ← NUEVO

#include <Servo.h>

// ---- Pins ----
#define MOTOR_IN1   6   // DRV8871 IN1 -> REV (LOW when forward)
#define MOTOR_IN2   5   // DRV8871 IN2 -> FWD (PWM)
#define SERVO_PIN   4   // MG995
#define LED_PIN     10
#define BUTTON_PIN  2   // Start button to GND (INPUT_PULLUP)

// Encoder NXT (quadrature A/B)
#define ENC_A 7        // OUT1
#define ENC_B 3        // OUT2 (interrupt)

// ---- Wheel / Encoder ----
const float WHEEL_DIAM_MM = 56.0f;
const int   PPR           = 360;

// ---- Motion params ----
const int  SERVO_CENTER   = 80;
const int  SERVO_RIGHT    = 130;     // tu valor actual (tune si hace falta)
const int  SERVO_LEFT     = 39;

const int  SPEED_FWD      = 190;     // avance constante
const int  SPEED_TURN     = 190;     // durante giro

// Giro por encoder (ARCO con servo fijo)
float TURN_RADIUS_MM = 200.0f;       // calibra para 90° exactos (radio asociado a SERVO_RIGHT/LEFT)

// Seguridad básica (solo para evitar bucle muerto en giro)
const unsigned long TURN_MAX_MS     = 2500;
const unsigned long START_DELAY_MS  = 2000;

// --- NUEVO: avance extra tras STOP ---
const float EXTRA_AFTER_STOP_MM     = 300.0f;     // 30 cm
const unsigned long EXTRA_DRIVE_MAX_MS = 4000;    // timeout por seguridad

// ---- State ----
enum Mode {IDLE, RUNNING, TURNING, HALT};
Mode mode = IDLE;

Servo sv;
volatile long encoderCount = 0;

// ---- Utils ----
void motorStop(){ digitalWrite(MOTOR_IN1,LOW); digitalWrite(MOTOR_IN2,LOW); }
void motorFwdPWM(int pwm){ pwm = constrain(pwm,0,255); digitalWrite(MOTOR_IN1,LOW); analogWrite(MOTOR_IN2,pwm); }
void steerAngle(int ang){ ang = constrain(ang,0,180); sv.write(ang); }

void resetEncoder(){ noInterrupts(); encoderCount = 0; interrupts(); }
long readEncoder(){ noInterrupts(); long c = encoderCount; interrupts(); return c; }

void encoderISR(){
  int a = digitalRead(ENC_A);
  int b = digitalRead(ENC_B);
  if (a == b) encoderCount++; else encoderCount--;
}

// s = R * theta;  pulses = s / (pi*D) * PPR
long pulsesForArc(float radius_mm, float theta_rad){
  float s = radius_mm * theta_rad;
  float wheel_circ = 3.1415926f * WHEEL_DIAM_MM;
  return (long)((s / wheel_circ) * (float)PPR + 0.5f);
}

// NUEVO: pulsos para distancia lineal
long pulsesForDistance(float dist_mm){
  float wheel_circ = 3.1415926f * WHEEL_DIAM_MM;
  return (long)((dist_mm / wheel_circ) * (float)PPR + 0.5f);
}

// NUEVO: avanzar en línea recta cierta distancia
void driveForwardDistanceMM(float dist_mm, int pwm, unsigned long timeout_ms){
  steerAngle(SERVO_CENTER);
  delay(80);
  long target = pulsesForDistance(dist_mm);
  resetEncoder();
  unsigned long t0 = millis();
  motorFwdPWM(pwm);
  while (true){
    if (readEncoder() >= target) break;
    if (millis() - t0 > timeout_ms) break;
  }
  motorStop();
}

// Botón con anti-rebote (press-release)
void waitButtonPressRelease(){
  while (digitalRead(BUTTON_PIN) == LOW) {}
  int last=HIGH, stable=HIGH; unsigned long t0=millis();
  for(;;){
    int r=digitalRead(BUTTON_PIN);
    if (r!=last){ last=r; t0=millis(); }
    if (millis()-t0>30){ if (r!=stable){ stable=r; if (stable==LOW) break; } }
  }
  last=LOW; stable=LOW; t0=millis();
  for(;;){
    int r=digitalRead(BUTTON_PIN);
    if (r!=last){ last=r; t0=millis(); }
    if (millis()-t0>30){ if (r!=stable){ stable=r; if (stable==HIGH) break; } }
  }
}

// Serial line reader
bool readLine(char* buf, int buflen, unsigned long timeout_ms){
  int idx=0; unsigned long t0=millis();
  while (millis()-t0<timeout_ms){
    while (Serial.available()){
      char c=(char)Serial.read();
      if (c=='\n'||c=='\r'){ if (idx>0){ buf[idx]=0; return true; } }
      else if (idx<buflen-1) buf[idx++]=c;
    }
  }
  buf[0]=0; return false;
}

// ---- Actions ----
void startRun(){
  Serial.println(F("GO"));          // avisa a la Pi
  // (sin centrado extra)
  resetEncoder();
  motorFwdPWM(SPEED_FWD);
  mode = RUNNING;
  digitalWrite(LED_PIN, HIGH);
}

// 90° RIGHT (arco con servo fijo)
void doTurnRight90_byEncoder(){
  mode = TURNING;

  steerAngle(SERVO_RIGHT);
  delay(120);                       // dar tiempo a que el servo llegue

  const float THETA = 3.1415926f * 0.5f;
  long targetPulses = pulsesForArc(TURN_RADIUS_MM, THETA);

  resetEncoder();
  unsigned long t0 = millis();
  motorFwdPWM(SPEED_TURN);

  while (true){
    long c = readEncoder();
    if (c >= targetPulses) break;
    if (millis() - t0 > TURN_MAX_MS) break;
  }

  motorStop();
  steerAngle(SERVO_CENTER);         // recenter SOLO al terminar el giro
  delay(120);

  resetEncoder();
  motorFwdPWM(SPEED_FWD);
  mode = RUNNING;
}

// 90° LEFT (arco con servo fijo)
void doTurnLeft90_byEncoder(){
  mode = TURNING;

  steerAngle(SERVO_LEFT);
  delay(120);

  const float THETA = 3.1415926f * 0.5f;
  long targetPulses = pulsesForArc(TURN_RADIUS_MM, THETA);

  resetEncoder();
  unsigned long t0 = millis();
  motorFwdPWM(SPEED_TURN);

  while (true){
    long c = readEncoder();
    if (c >= targetPulses) break;
    if (millis() - t0 > TURN_MAX_MS) break;
  }

  motorStop();
  steerAngle(SERVO_CENTER);
  delay(120);

  resetEncoder();
  motorFwdPWM(SPEED_FWD);
  mode = RUNNING;
}

// NUDGE: solo servo, no cambia la velocidad
void doNudge(int sign, int deg, int ms){
  if (mode != RUNNING) return;
  deg = constrain(deg, 0, 40);
  int target = SERVO_CENTER + (sign>0 ? deg : -deg);
  steerAngle(target);
  delay(ms);
  steerAngle(SERVO_CENTER);
}

// STOP: ahora hace 30 cm extra y frena (servo centrado)  ← NUEVO
void doStop(){
  // Avance extra controlado por encoder
  driveForwardDistanceMM(EXTRA_AFTER_STOP_MM, SPEED_FWD, EXTRA_DRIVE_MAX_MS);
  // Parada final
  motorStop();
  mode = HALT;
  digitalWrite(LED_PIN, LOW);
}

// ---- Setup/Loop ----
void setup(){
  Serial.begin(115200);

  pinMode(MOTOR_IN1,OUTPUT);
  pinMode(MOTOR_IN2,OUTPUT);
  pinMode(LED_PIN,OUTPUT);
  pinMode(BUTTON_PIN,INPUT_PULLUP);

  pinMode(ENC_A,INPUT_PULLUP);
  pinMode(ENC_B,INPUT_PULLUP);
  attachInterrupt(digitalPinToInterrupt(ENC_B), encoderISR, CHANGE);

  sv.attach(SERVO_PIN);
  steerAngle(SERVO_CENTER);   // posición base
  motorStop();
  digitalWrite(LED_PIN, LOW);
  mode = IDLE;
}
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

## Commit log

2025-08-13 Rename Motor mount 0.1.SLDPRT to Old models/Motor mount 0.1.SLDPRT
    [Motor mount 0.1.SLDPRT]
2025-08-13 Rename lower base 0.1.SLDPRT to Old models/lower base 0.1.SLDPRT
    [lower base 0.1.SLDPRT]
2025-08-13 Rename upper base 0.1.SLDPRT to Old models/upper base 0.1.SLDPRT
    [upper base 0.1.SLDPRT]
2025-09-11 Arduino Nano Code - Open Challenge
2025-10-06 Update README.md
    battery change
2025-10-19 Added the fist version of the ColorCalibrator program that will help us calibrate color recognition in different light conditions
2025-10-23 Added updated wiring diagram with servo capacitor and push botton in D2
2025-10-23 Deleted old wiring diagram
2025-10-23 Uploaded a power topology diagram
2025-10-24 Create Electrical_Electronics_Report_Rulobot.md
    Uploaded the new Electrical_Electronics_Report_Rulobot and after deleting de old one that was on pdf, we did this because its easier to edit and modify it in this way
2025-11-09 Added obstacle challenge video + sections 7–10 (Management, Testing, Risks, Maintenance)
2025-11-09 add sections 10–14 (maintenance, efficiency, validation, lessons, conclusion)
2025-11-10 Changed NanoOpenAndClosed.ino name to RuloBot.ino for cleaner look and some minor changes
    Updated the Arduino Nano firmware to unify control for both OPEN and CLOSED rounds using a single sketch. The main change sets the forward speed (SPEED_FWD) to 255 for the OPEN round, with the option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
2025-11-10 Changed name to OpenChallenge.py for a cleaner look and some major changes
    migrated color segmentation to a dual-path system with optional LAB Mahalanobis models loaded from JSON (keeps HSV as fallback), widened the bottom line ROI (≈ 0.20–0.80 vs 0.25–0.75) and slightly retuned front/TOP stop ROIs for earlier, cleaner triggers, tightened white-glare suppression and exposed the morphology Kernel + thresholds more clearly in the TUNING panel, made the line-color decision more robust with stability counters and a margin, added/kept side-PD soft-start and explicit front-black hysteresis with smoother blending during turns, and polished logging/HUD while maintaining the serial protocol and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
    [OpenChallenge.py]
2025-11-10 Revise Electrical and Electronics Documentation
    Updated the Electrical and Electronics Documentation for Team Rulo Bot to enhance clarity, detail, and formatting. Added sections on system architecture, control units, vision system, actuation syste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
2025-11-14 Update ObstacleChallenge.py
    This new version of the obstacle challenge is compatible with out parking logic and the ObstacleIno.ino code, it is able to exit the parking succesfully and avoid the obstacles.
    [ObstacleChallenge.py]
2025-11-15 Update ObstacleChallenge.py
    It now chooses orientation better in corner turns and evades better in result of changes in the pid
